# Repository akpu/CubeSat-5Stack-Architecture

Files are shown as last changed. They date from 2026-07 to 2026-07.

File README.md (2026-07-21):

# Open-Source ESP32 CubeSat 5-Stack Electronics Architecture with LoRa, APRS, SSTV and WSPR Telemetry 🛰️

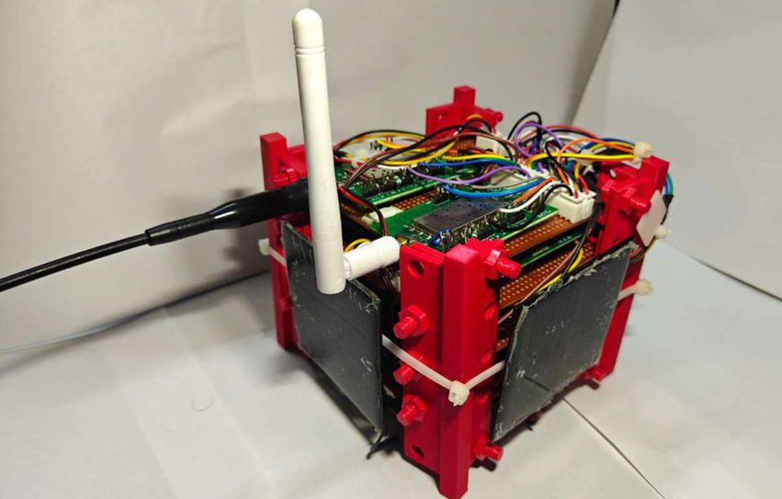
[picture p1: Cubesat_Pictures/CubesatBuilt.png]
CubeSat Assembly


A modular **1U CubeSat electronic stack** developed for balloon-based communication and telemetry experiments.

This project focuses on the design, development, integration, and validation of a complete CubeSat electronics platform consisting of five modular PCB subsystems, embedded firmware, ground station software, and 3D mechanical integration.

---

# System Architecture

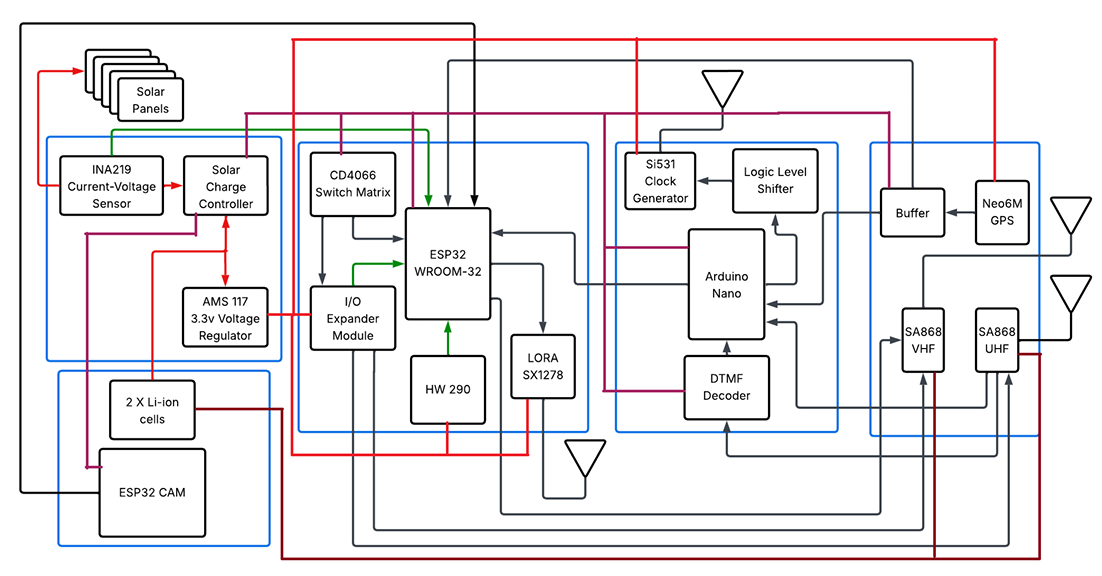
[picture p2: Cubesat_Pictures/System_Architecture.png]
System Architecture


The CubeSat architecture consists of five modular subsystems:

1. Communication Board  
2. Main On-Board Computer (OBC) Board  
3. Secondary Controller Board  
4. Power Management Board  
5. Battery and Payload Board  

---

# Hardware Implementation

The electronics system was designed using **KiCad** with custom schematic and PCB layouts.

Main hardware components:

- ESP32-WROOM-32 based On-Board Computer
- Arduino Nano secondary controller
- LoRa SX1278 telemetry transceiver
- SA868 VHF/UHF communication module
- ESP32-CAM SSTV imaging payload
- Si5351 WSPR beacon transmitter
- Neo-6M GPS module
- HW-290 IMU sensor
- INA219 power monitoring sensor

---

# PCB Stack Assembly

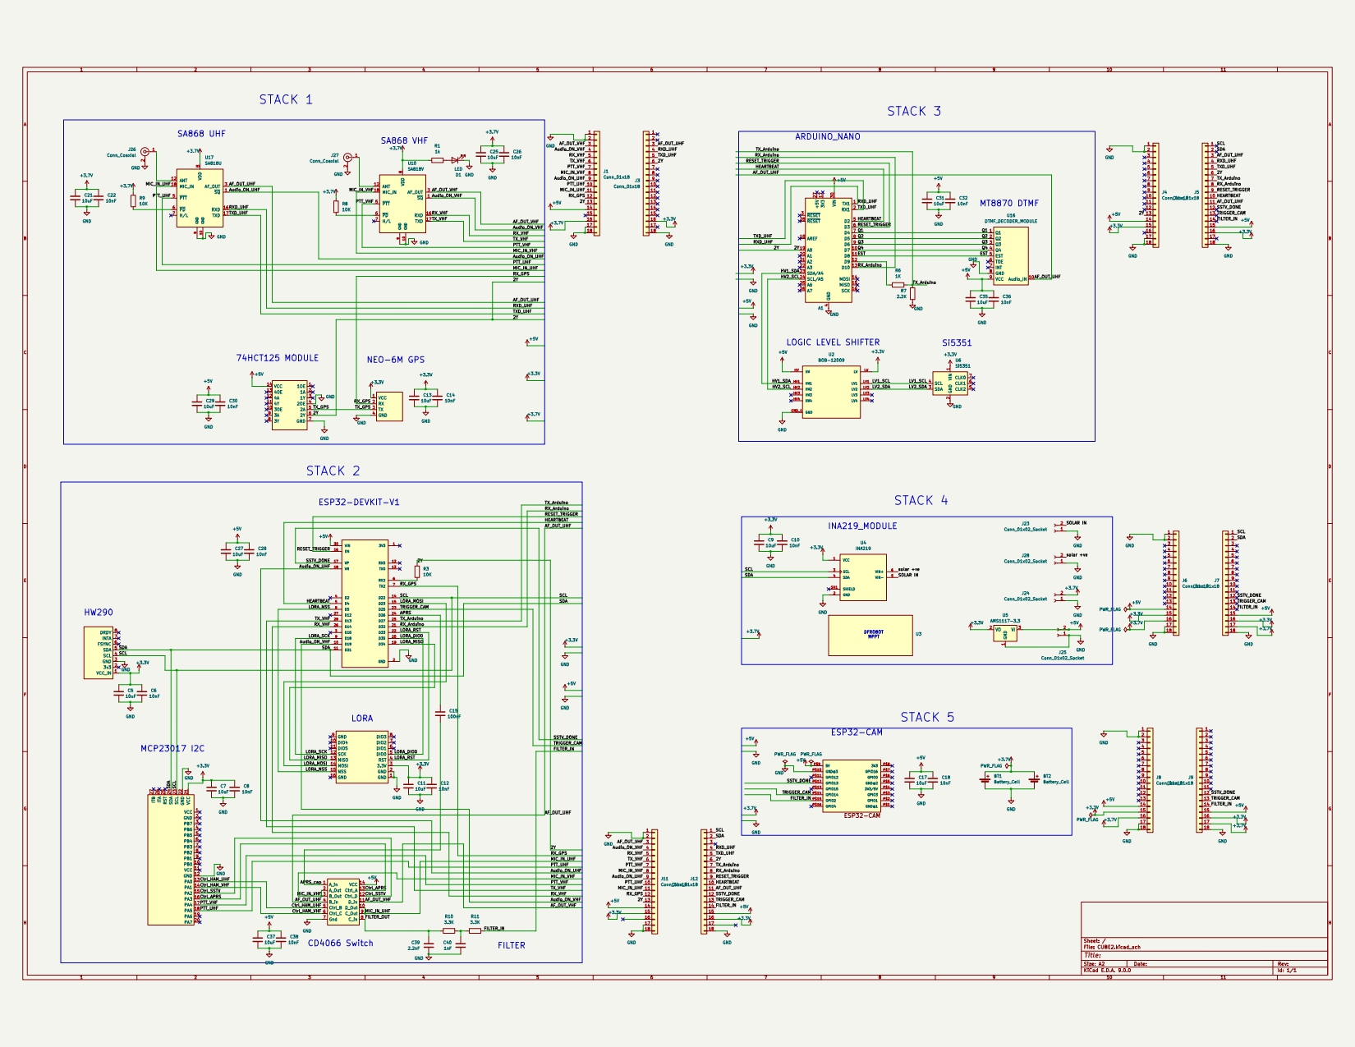
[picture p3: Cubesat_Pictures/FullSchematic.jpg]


The CubeSat electronics were implemented as five vertically stacked PCB modules.

PCB design files are available in:

```
Hardware_Design/
```

Includes:

- KiCad schematic files (`.kicad_sch`)
- PCB layout files (`.kicad_pcb`)
- KiCad project files (`.kicad_pro`)

---
---

<h2>Individual PCB Stack Modules</h2>

<table>
<tr>
<td align="center">
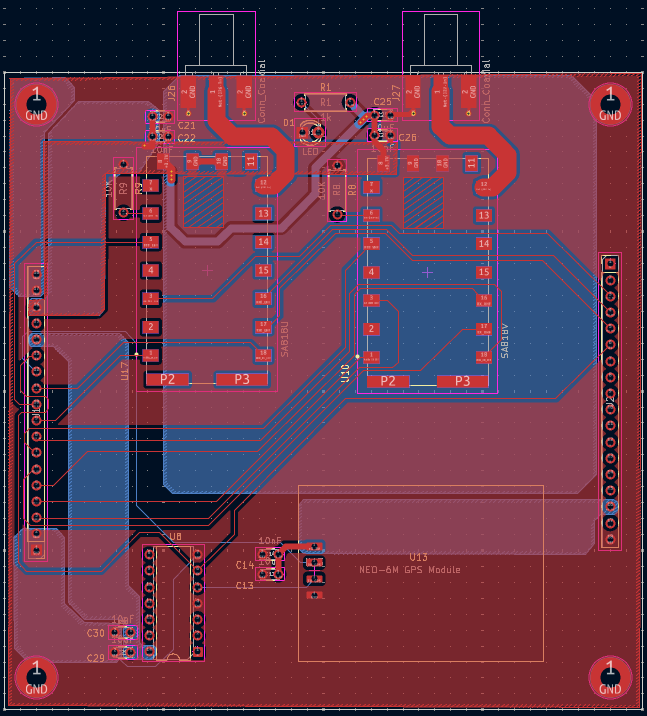
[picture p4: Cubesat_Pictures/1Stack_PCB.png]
<br>
<b>Communication Board</b>
</td>

<td align="center">
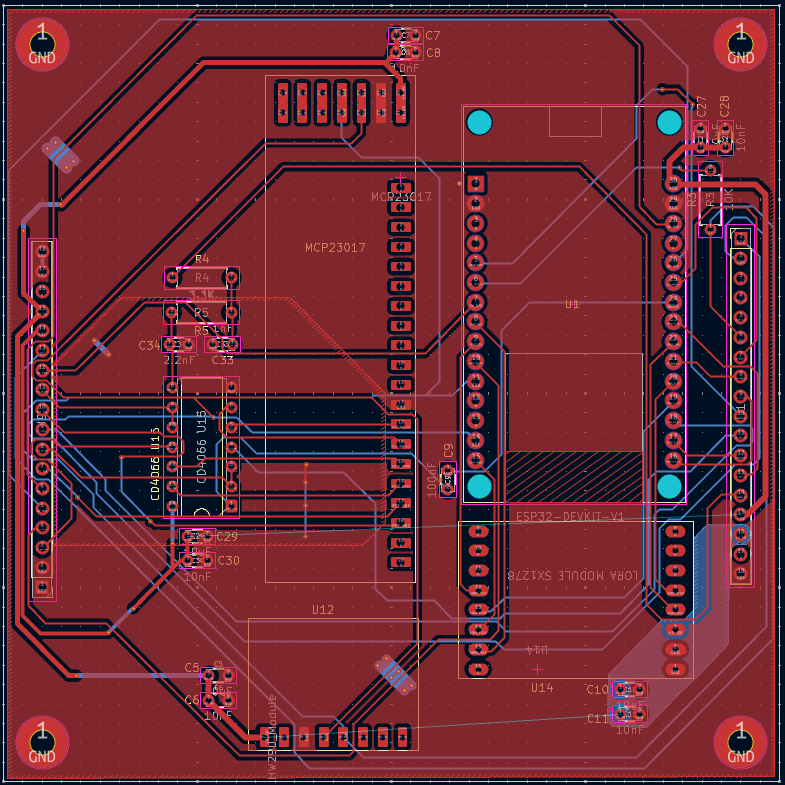
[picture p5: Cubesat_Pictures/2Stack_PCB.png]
<br>
<b>Main OBC Board</b>
</td>

<td align="center">
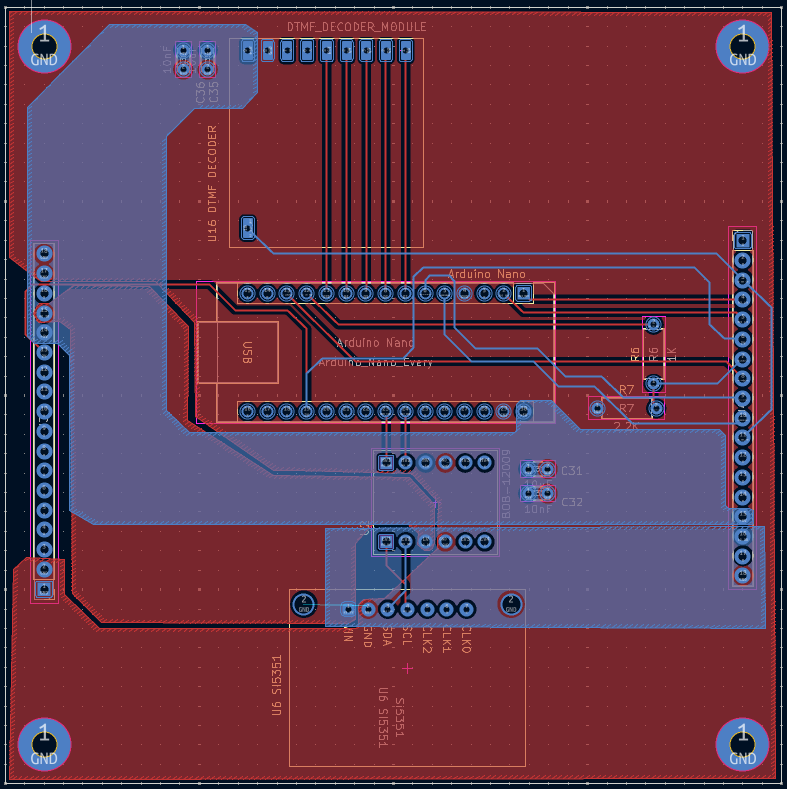
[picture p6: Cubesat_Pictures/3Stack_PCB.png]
<br>
<b>Secondary Controller Board</b>
</td>
</tr>

<tr>
<td align="center">
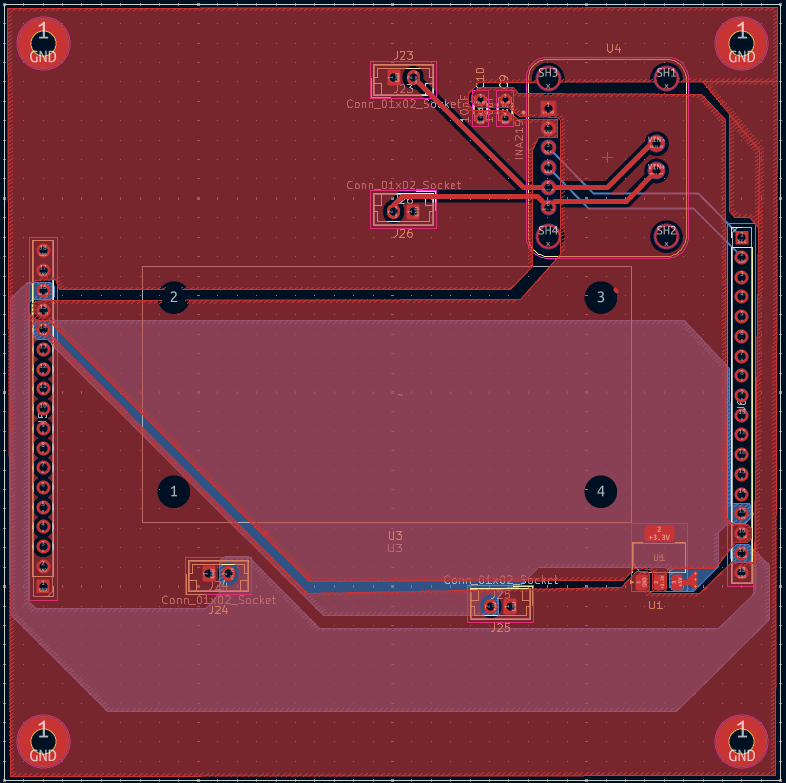
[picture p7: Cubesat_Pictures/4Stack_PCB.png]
<br>
<b>Power Management Board</b>
</td>

<td align="center">
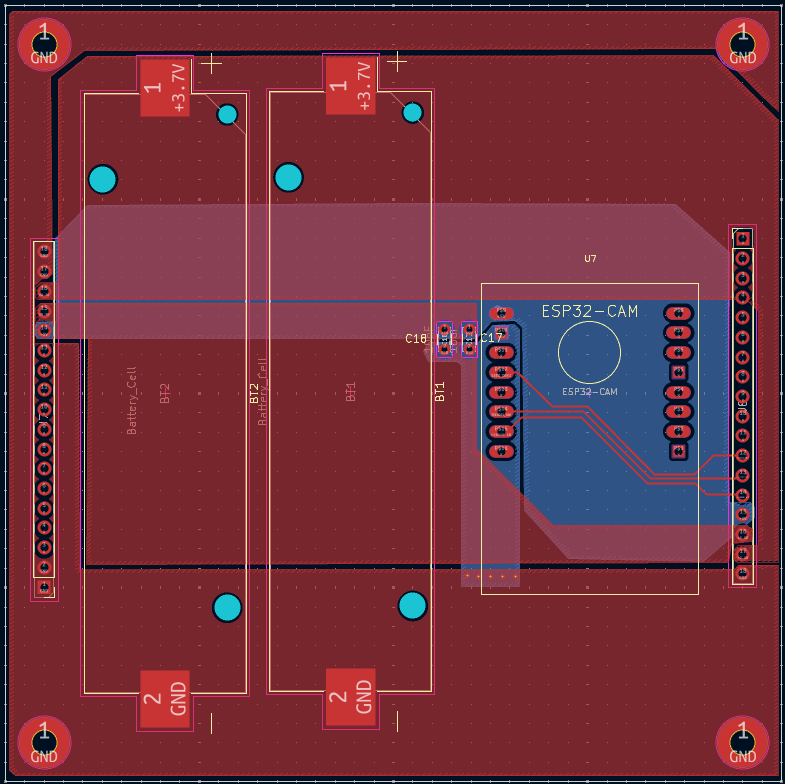
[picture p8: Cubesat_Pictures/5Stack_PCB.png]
<br>
<b>Battery & Payload Board</b>
</td>
</tr>
</table>

# 3D Design

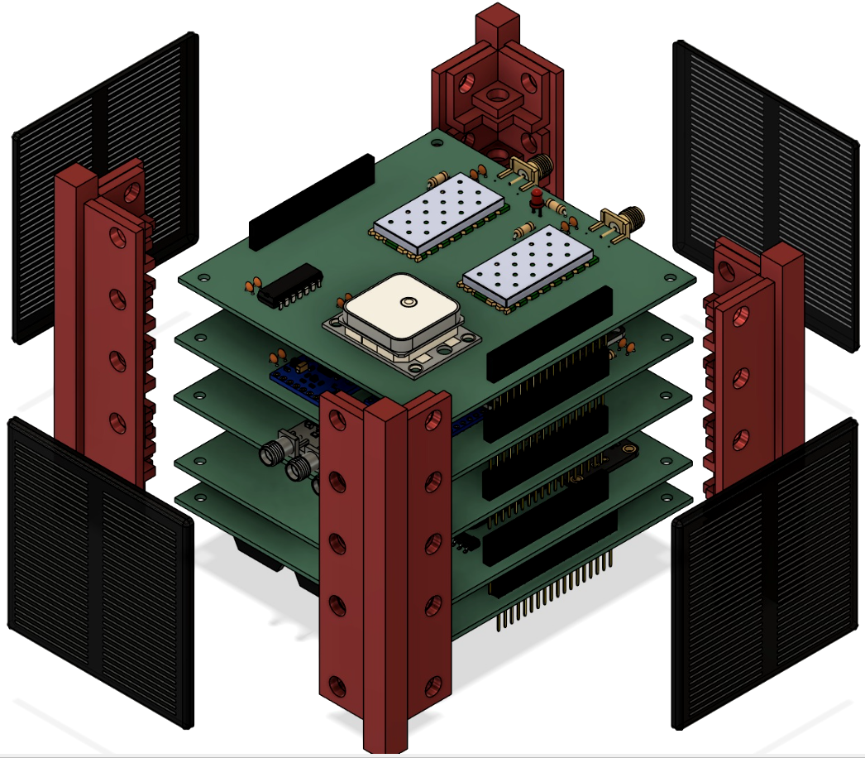
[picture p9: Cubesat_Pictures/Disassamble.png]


The complete CubeSat mechanical structure was designed using:

- Fusion 360

Includes:

- PCB stack integration
- Structural frame design
- Component placement visualization
- Complete assembly model
<h2>Individual PCB Stack Modules</h2>

<table>
<tr>
<td align="center">
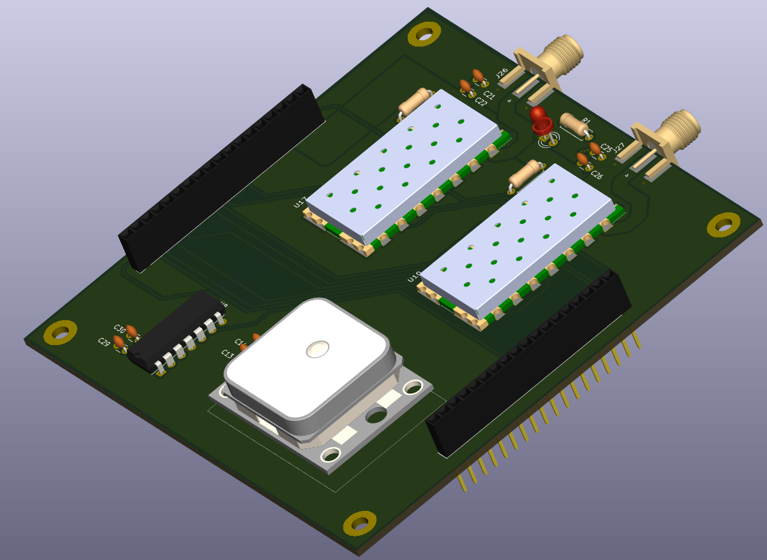
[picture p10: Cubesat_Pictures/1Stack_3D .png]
<br>
<b>Communication Board</b>
</td>

<td align="center">
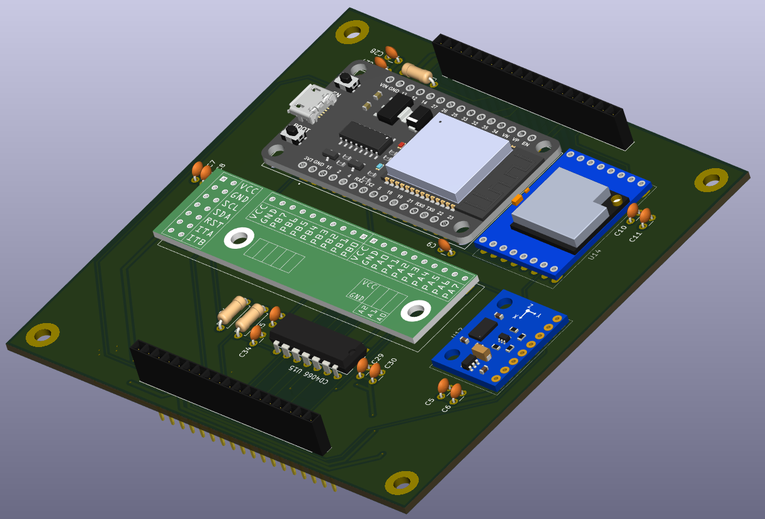
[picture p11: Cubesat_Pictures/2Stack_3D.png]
<br>
<b>Main OBC Board</b>
</td>

<td align="center">
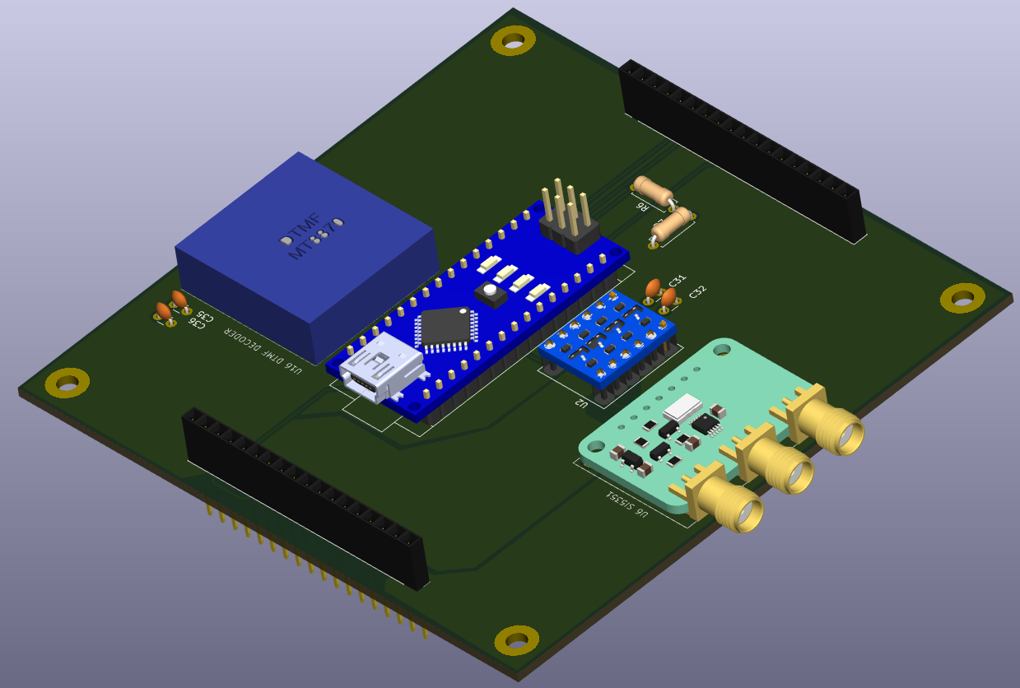
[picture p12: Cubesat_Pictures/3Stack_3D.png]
<br>
<b>Secondary Controller Board</b>
</td>
</tr>

<tr>
<td align="center">
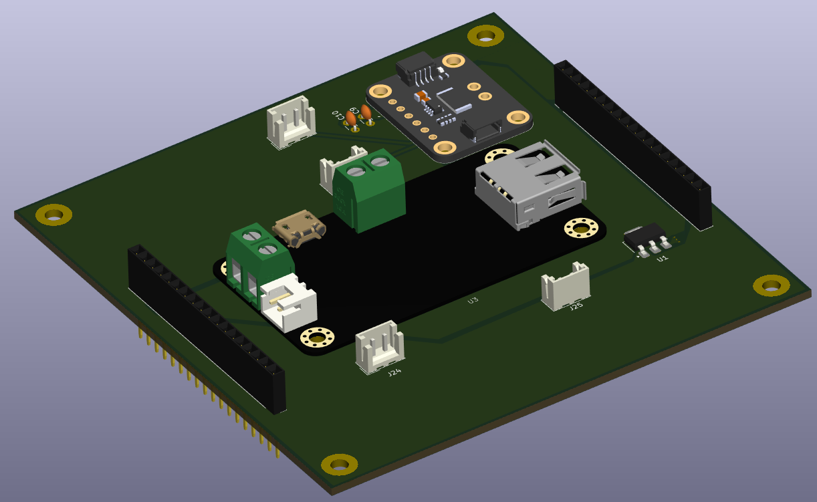
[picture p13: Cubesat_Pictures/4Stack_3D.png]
<br>
<b>Power Management Board</b>
</td>

<td align="center">
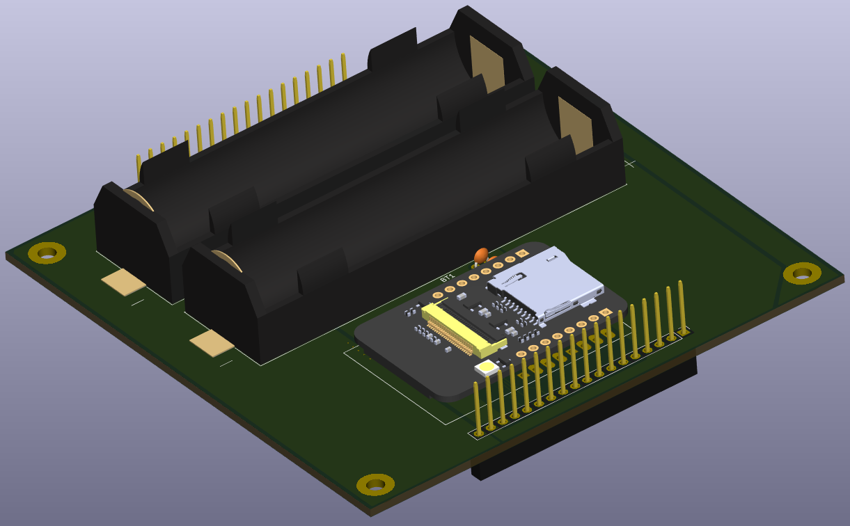
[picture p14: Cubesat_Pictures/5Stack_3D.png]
<br>
<b>Battery & Payload Board</b>
</td>
</tr>
</table>
Files:

```
3D_Design/
```

---

# Firmware Development

Embedded firmware was developed for:

```
Firmware/
```

Includes:

### CubeSat Onboard Firmware

- ESP32 main controller code
- ESP32-CAM SSTV payload code
- Arduino Nano WSPR beacon code

### Ground Station Software

A web-based dashboard was developed for real-time telemetry visualization.

Features:

- GPS position monitoring
- Altitude display
- Sensor data visualization
- Solar Charging monitoring
- Orientation information

---

# Ground Station

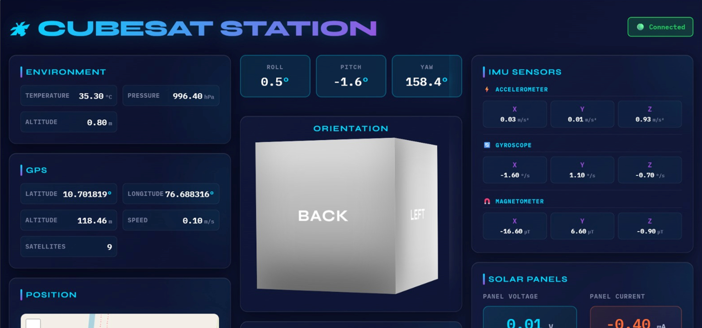
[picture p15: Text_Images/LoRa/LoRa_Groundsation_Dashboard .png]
Ground Station Dashboard


The ground station receives and displays telemetry transmitted from the CubeSat system.

---

# Testing and Validation

The system was validated through rooftop ground-based experiments.

Validated communication modes:

✅ LoRa telemetry transmission  
✅ APRS communication  
✅ SSTV image transmission  
✅ WSPR beacon decoding  

Detailed test results and screenshots:

```
Text_Images/
```

---

# Testing Video

Rooftop demonstration video showing:

- Integrated CubeSat hardware
- Communication testing
- Ground station operation

((https://drive.google.com/file/d/1SzN-sQUl8R-h_qq5jK-UIxGzSsxhfScu/view?usp=drivesdk))

---

# Documentation

Complete project documentation:

```
Documentation/
```

Includes:

- Complete CubeSat Project Report
- Complete System Schematic

---

# Repository Structure

```
CubeSat-5Stack-Architecture

├── Documentation
├── Hardware_Design
├── 3D_Design
├── Firmware
├── Calculations
├── Cubesat_Pictures
├── Text_Images
├── Testing_Video
└── README.md
```

---

# Project Team

**B.Tech Final Year Project**  
Department of Electronics and Communication Engineering  
NSS College of Engineering, Palakkad

Team Members:

- Abhishek B
- Akshay S
- Arunkrishna P U
- Kiran S M

---

# Acknowledgement

Developed as part of the B.Tech Final Year Project under the Department of Electronics and Communication Engineering, NSS College of Engineering, Palakkad.

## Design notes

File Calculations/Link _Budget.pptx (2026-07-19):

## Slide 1

Link Margin = Pr − Sensitivity

Link Margin: Difference between received power and receiver sensitivity; positive margin means reliable communication.

• Pt – Transmit power (dBm)
• Gt, Gr – Antenna gains (dBi)
• FSPL – Free-space path loss
• Losses – Cable, connectors, mismatch, fade
• Sensitivity – Receiver minimum detectable power

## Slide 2

VHF Antenna (at Cubesat & Ground Station)

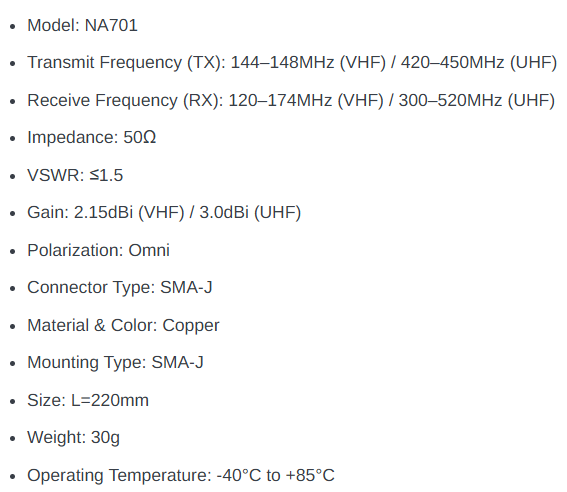
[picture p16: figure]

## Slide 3

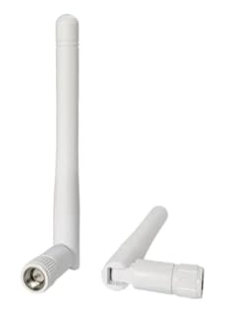
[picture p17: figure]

Lora Antenna for Uplink and Downlink

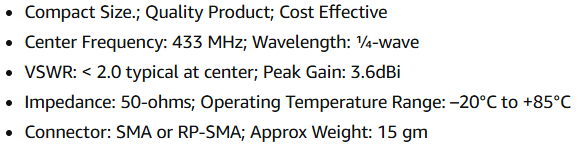
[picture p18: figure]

FSPL CALCULATION (433MHz LoRa)
LFSPL = 32.44 + 20log(433) + 20log(30)
TOTAL FSPL = 32.44 + 52.730 + 29.542 = 114.712 dB

FSPL CALCULATION (145MHz VHF)
LFSPL = 32.44 + 20log(145) + 20log(30)
TOTAL FSPL = 32.44 + 23.223 + 29.542 = 105.205 dB

FSPL CALCULATION (445MHz UHF)
LFSPL = 32.44 + 20log(430) + 20log(30)
TOTAL FSPL = 32.44 + 52.967 + 29.542 = 114.95 dB

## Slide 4

VHF (NA701 Antenna)

Parameter | Value | dB
TX Power (Pt) | 2W SA818 | +33.01 dBm
CubeSat Ant (Gt) | NA701 Quartz | +2.15 dBi
Free Space Loss | 30km @ 145MHz | -105.20 dB
Ground Ant (Gr) | NA701 Quartz | +2.15 dBi
Misc Losses | Cables/Polar | -1.0 dB
Received Power (Pr) | | -71.90 dBm
RTL-SDR Sensitivity | | -110 dBm
LINK MARGIN | | +38.10 dB

UHF (NA701 Antenna)

Parameter | Value | dB
TX Power (Pt) | 2W SA818 | +33.01 dBm
CubeSat Ant (Gt) | NA701 Quartz | +3 dB
Free Space Loss | 30km @ 445MHz | -114.95 dB
Ground Ant (Gr) | NA701 Quartz | +3 dB
Misc Losses | Cables/Polar | -1.0 dB
Received Power (Pr) | | -74.79 dBm
RTL-SDR Sensitivity | | -110 dBm
LINK MARGIN | | +35.21 dB

LoRa Antenna 433Mhz

Parameter | Value | dB
TX Power (Pt) | 100mW SX1278 | +20.00 dBm
CubeSat Ant (Gt) | Sharvi Lora 433MHz | +3.60 dBi
Free Space Loss | 30km @ 433MHz | -114.71 dB
Ground Ant (Gr) | Sharvi Lora 433MHz | +3.60 dBi
Misc Losses | Cables/SWR | -1.0 dB
Received Power (Pr) | | -90.51 dBm
RTL-SDR Sensitivity | | -137 dBm
LINK MARGIN | | +46.49 dB

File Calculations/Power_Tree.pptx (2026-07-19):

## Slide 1

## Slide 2

POWER TREE

DFR0559

5V, 1A

462.4mA

19mA

90mA

150mA

AMS1117S 3.3

191mA

2mA

I/O Expander

3V3, 1A

15.5mA

Si5351

3.7 V, 3.4Ah

2P LGMJI18650

Arduino NANO

2mA

INA219

80mA

NEO 6M

ESP32 WROOM 32

8.5mA

HW-290

ESP32 CAM

83mA

SX1278(Lora)

Req. Energy / hour | 3.36 Wh
Max battery energy | 25.16 Wh
Usable energy (70%) | 17.61 Wh
Backup time | ≈ 5.2 h
Est. Flight Time | = 3-4 h

0.4mA

74HCT125

1060mA

9mA

DTMF

60mA

SA868 (VHF)

1000mA

SA868 (UHF)

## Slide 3

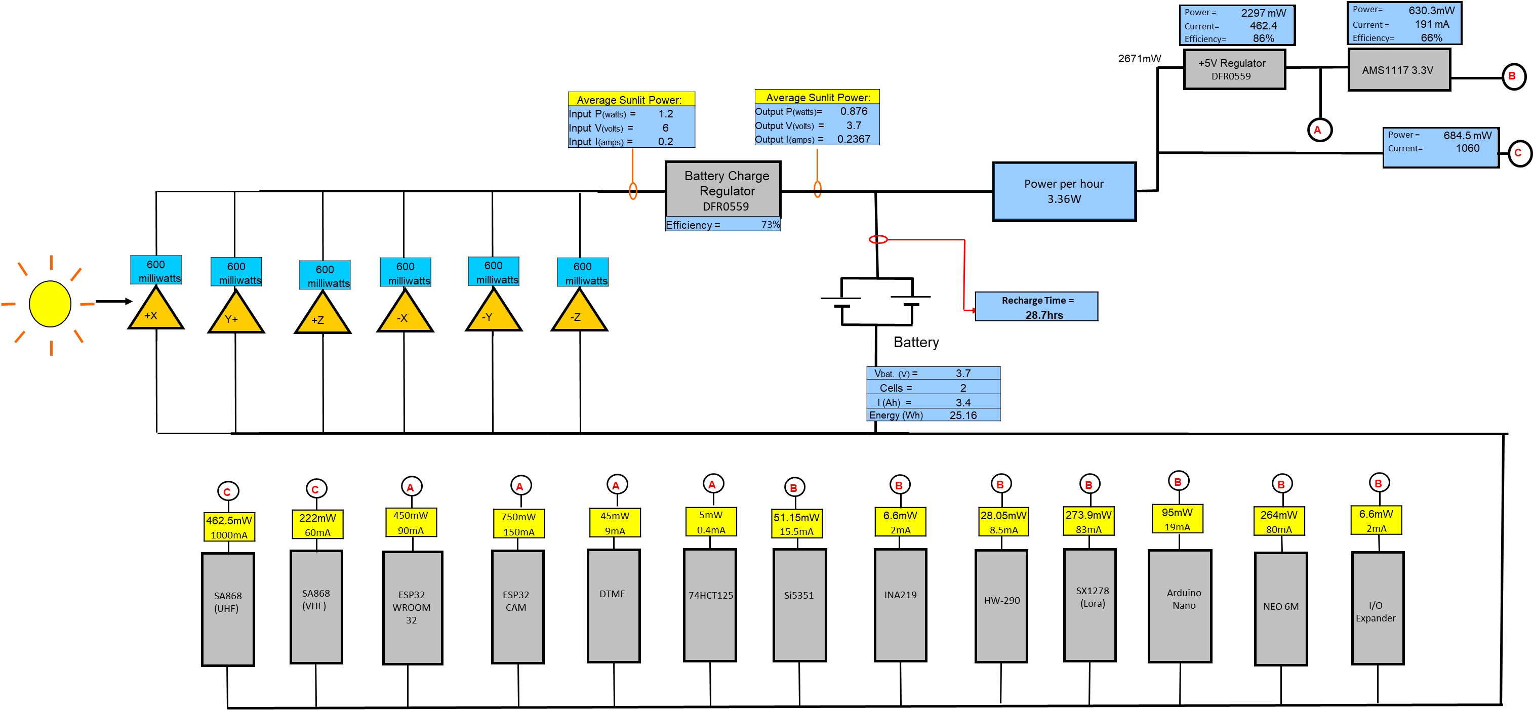
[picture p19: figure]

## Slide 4

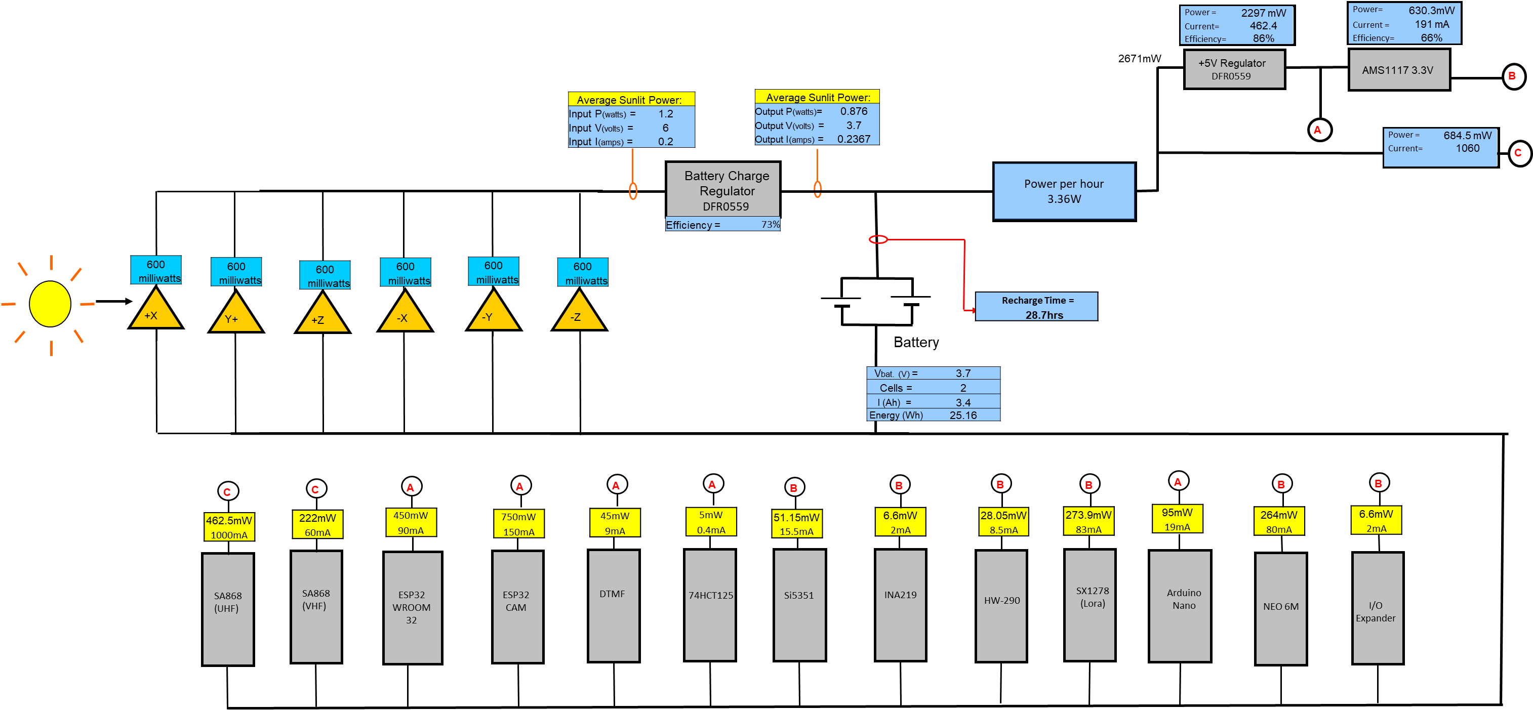
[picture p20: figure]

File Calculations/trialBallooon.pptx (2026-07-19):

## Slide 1

PERMISSION and REGULATIONS

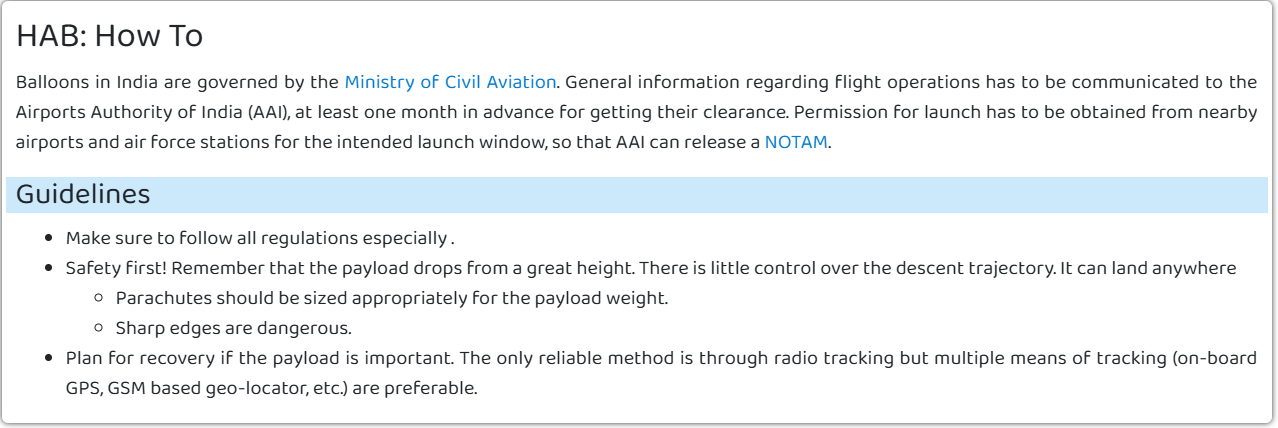
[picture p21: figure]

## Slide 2

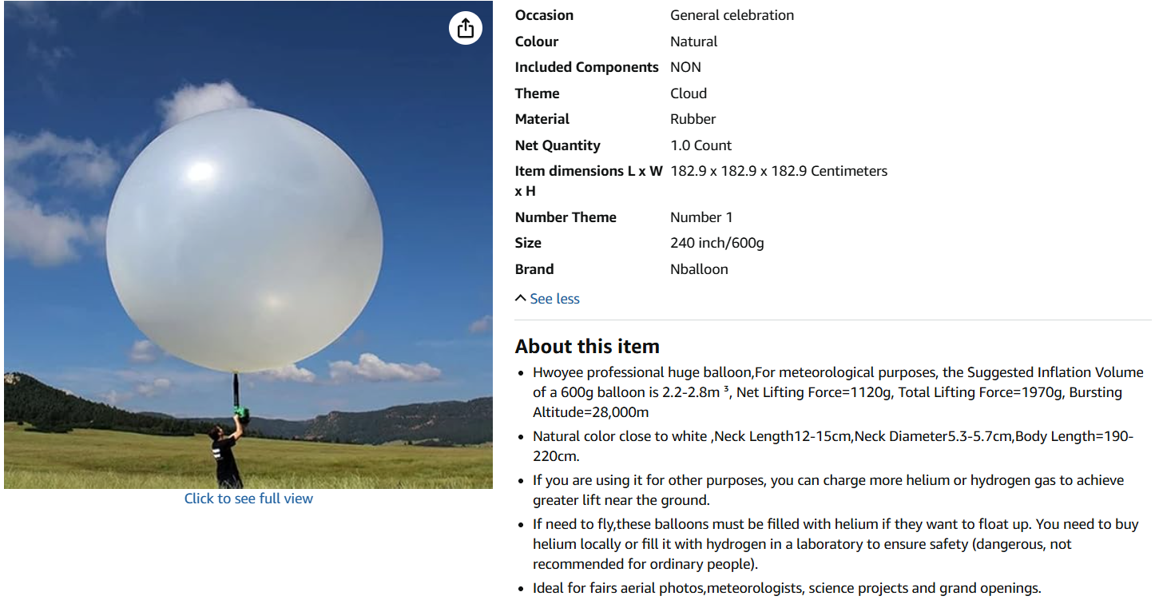
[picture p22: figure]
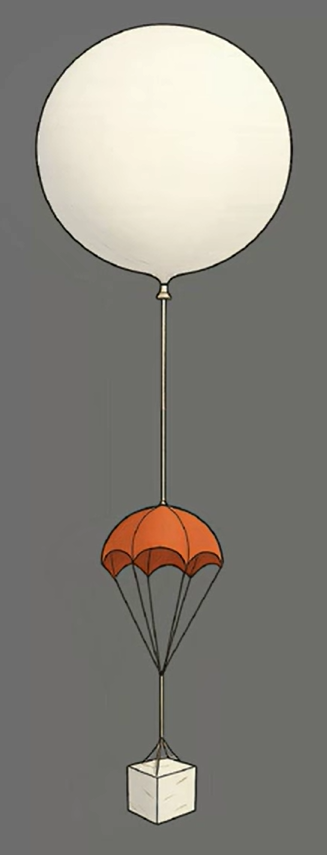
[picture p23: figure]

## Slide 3

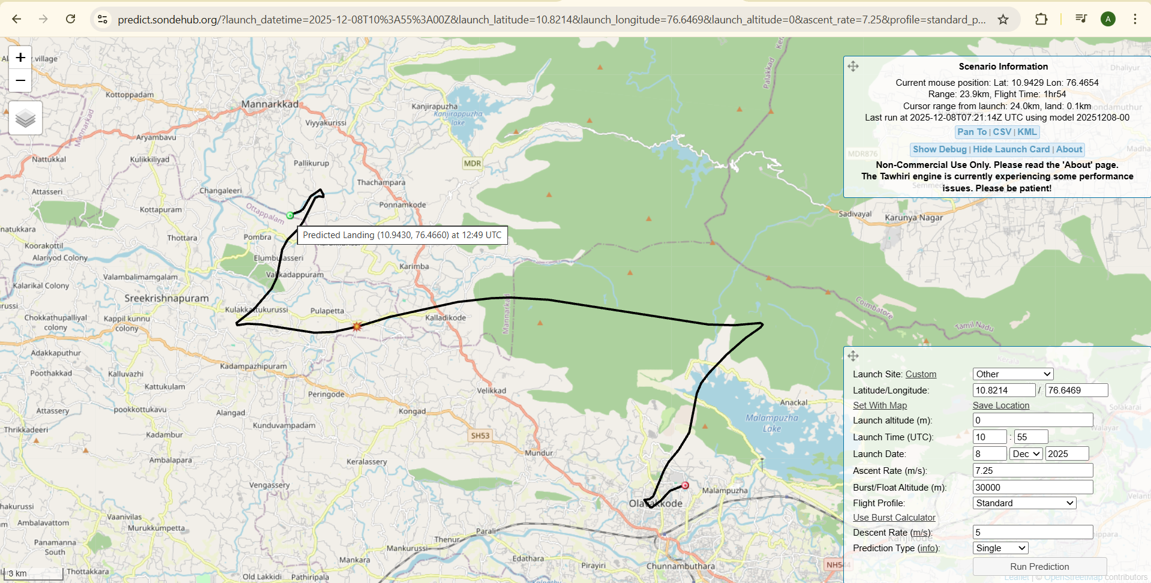
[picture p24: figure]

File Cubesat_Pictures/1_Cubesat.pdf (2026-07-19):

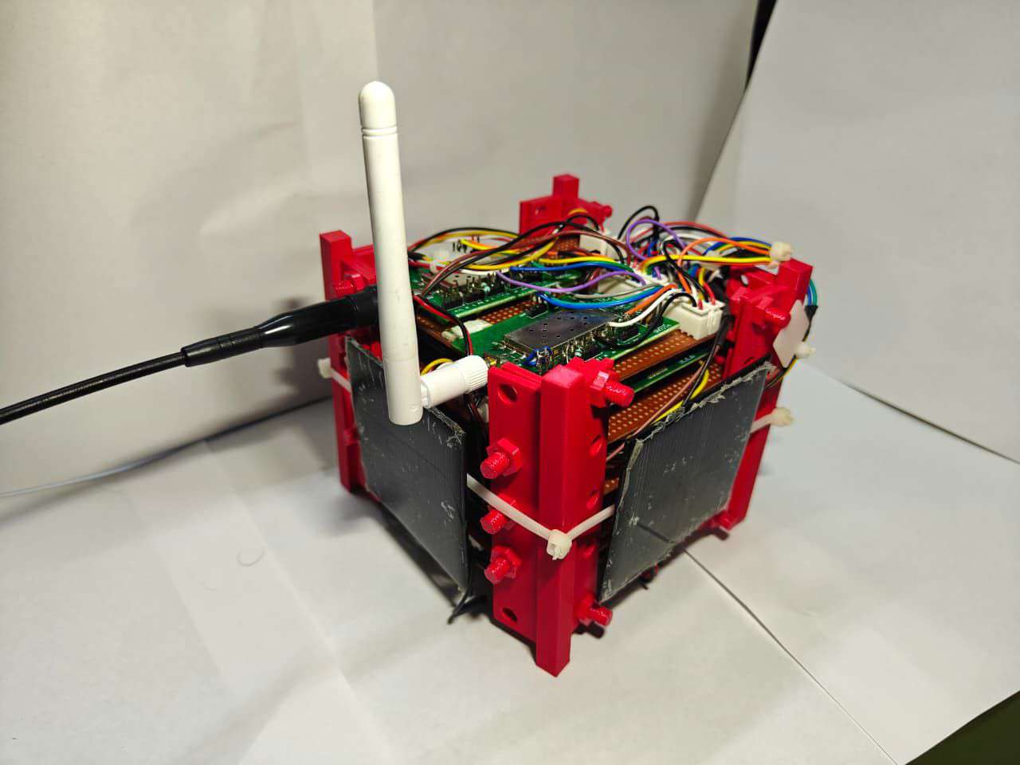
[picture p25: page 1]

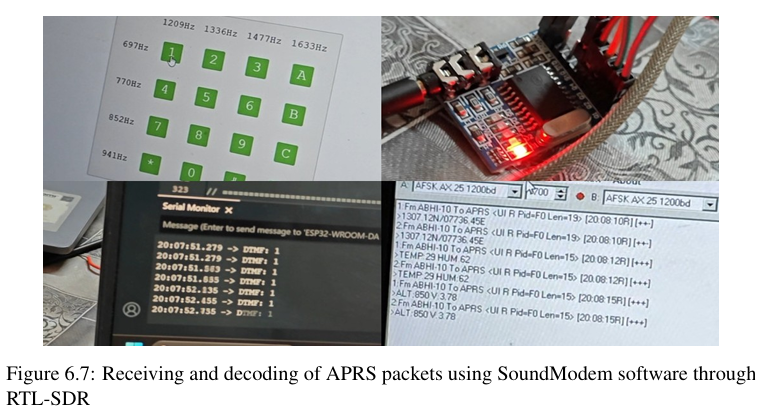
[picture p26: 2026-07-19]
Text_Images/APRS/Tx&Rx.png

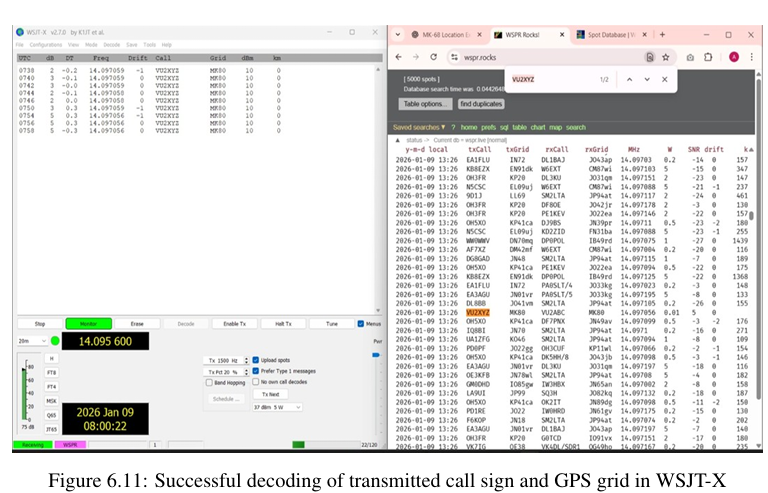
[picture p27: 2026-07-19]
Text_Images/WSPR/WSJT-X.png

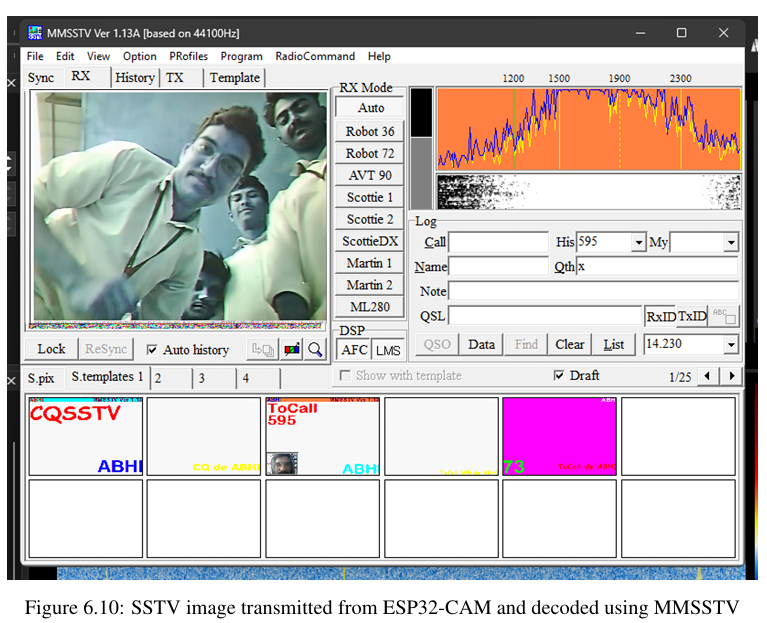
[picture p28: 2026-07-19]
Text_Images/SSTV/SSTV_trial.png

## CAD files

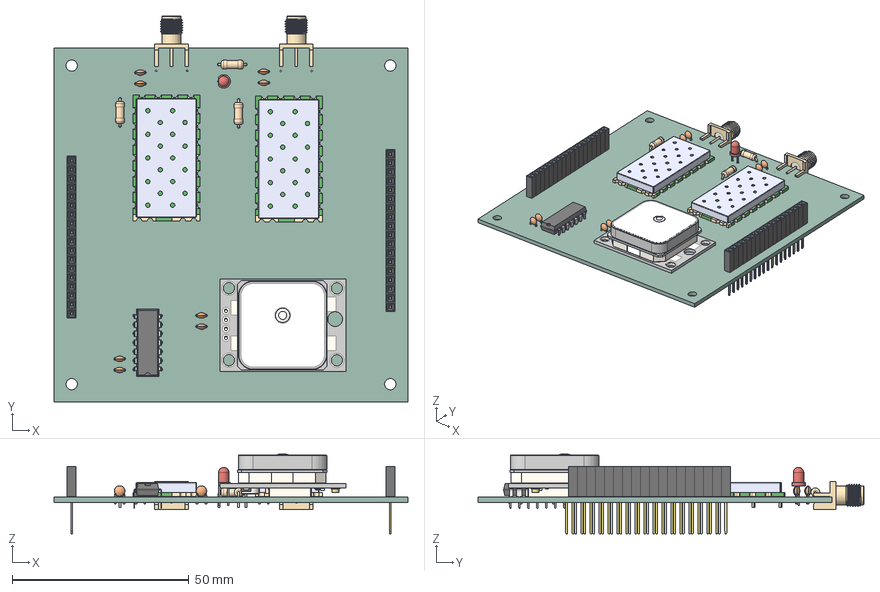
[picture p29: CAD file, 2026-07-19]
Hardware_Design/Stack_1_Communication/1stack.step
100.0 x 109.0 x 22.5 mm
DIP-14_W7.62mm
SIL_Socket_Body x 2
SIL_SocketPin x 2
GPS_ublox_board
GPS_board
GPS_ant
GPS_back
C_Disc_D3.0mm_W1.6mm_P2.50mm x 8
R_Axial_DIN0207_L6.3mm_D2.5mm_P7.62mm_Horizontal x 3
SMA_Molex_73251-1153_EdgeMount_Horizontal x 2
DRA818V x 2
LED_D3.0mm
1stack_PCB

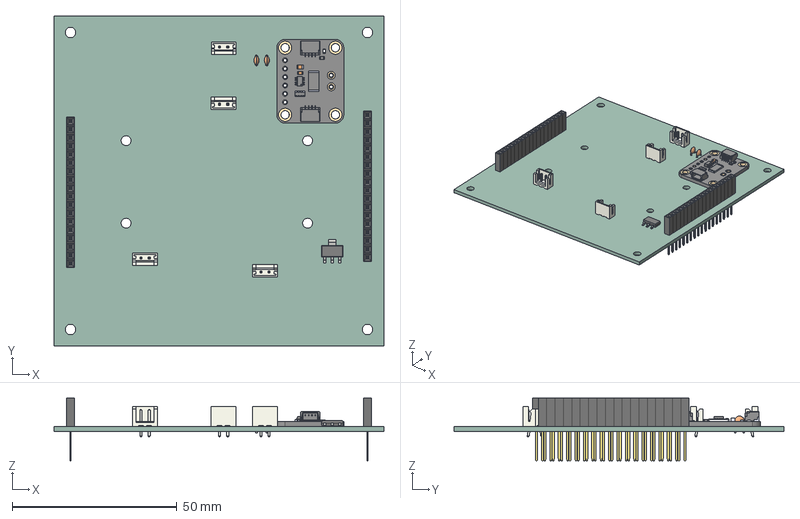
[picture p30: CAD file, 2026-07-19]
Hardware_Design/Stack_4_Power_Management/4 stack.step
100.0 x 100.0 x 19.0 mm
JST_EH_B2B-EH-A_1x02_P2.50mm_Vertical x 4
SOT-223
INA219BIDCNT_INA219BIDCNT1
SM04B-SRSS-TB(LF)(SN) x 2
SIL_Socket_Body x 2
SIL_SocketPin x 2
C_Disc_D3.0mm_W1.6mm_P2.50mm x 2
4 stack_PCB

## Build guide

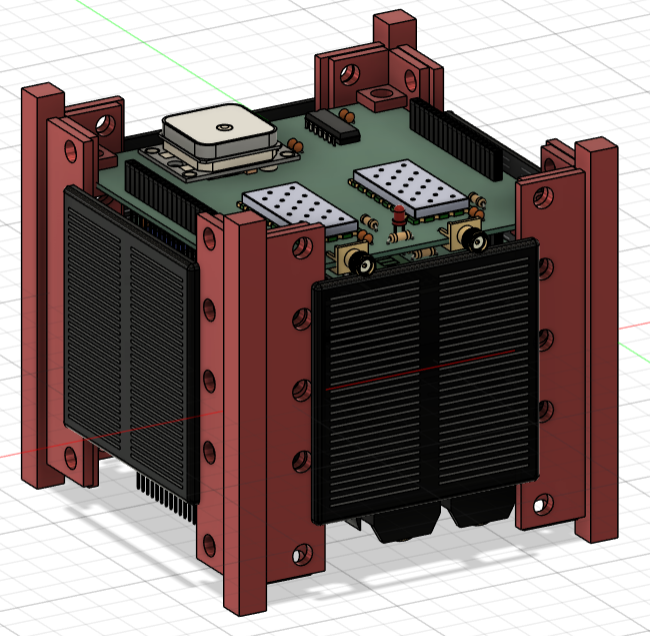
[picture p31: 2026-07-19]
Cubesat_Pictures/FULLASSEMBLE.png

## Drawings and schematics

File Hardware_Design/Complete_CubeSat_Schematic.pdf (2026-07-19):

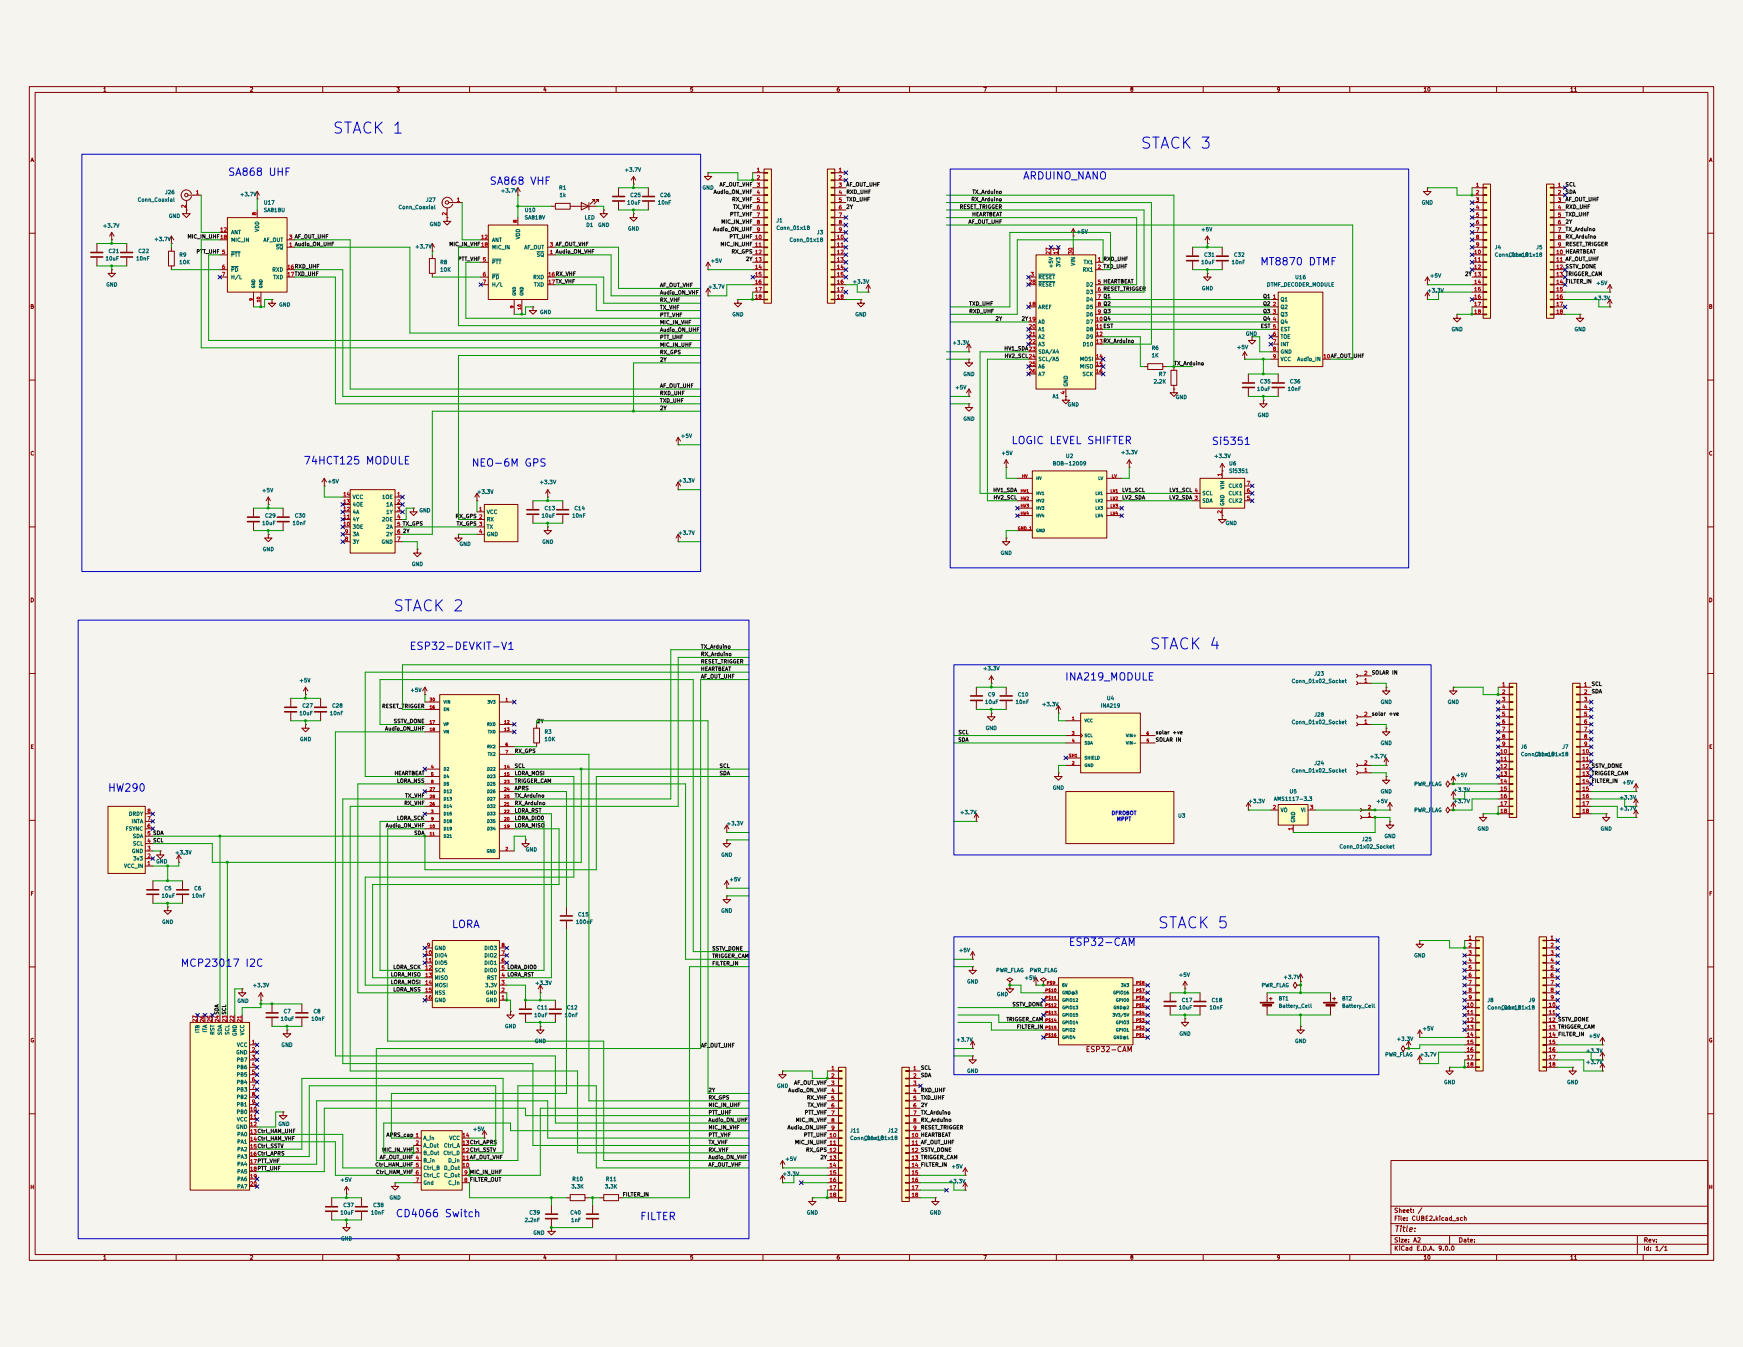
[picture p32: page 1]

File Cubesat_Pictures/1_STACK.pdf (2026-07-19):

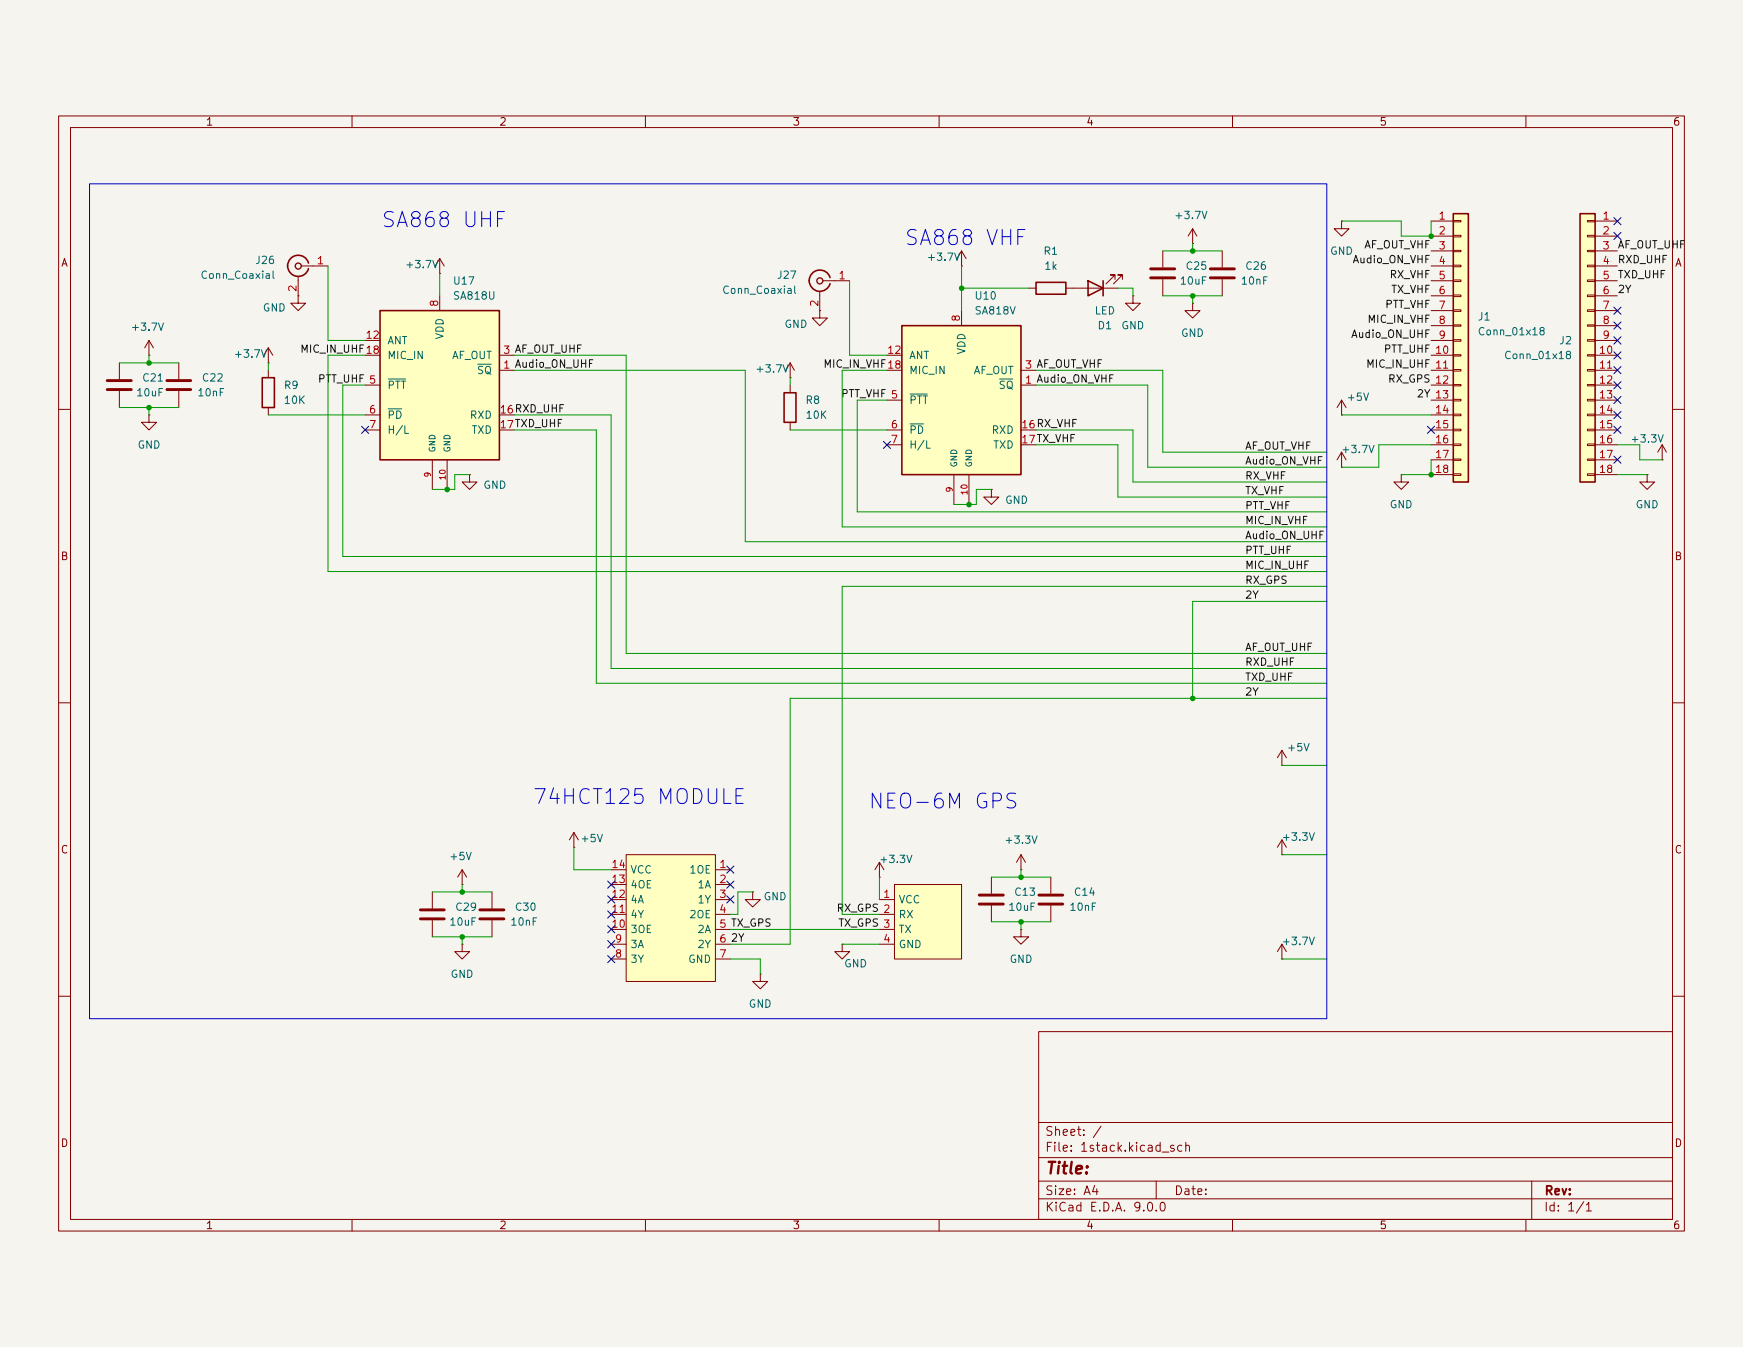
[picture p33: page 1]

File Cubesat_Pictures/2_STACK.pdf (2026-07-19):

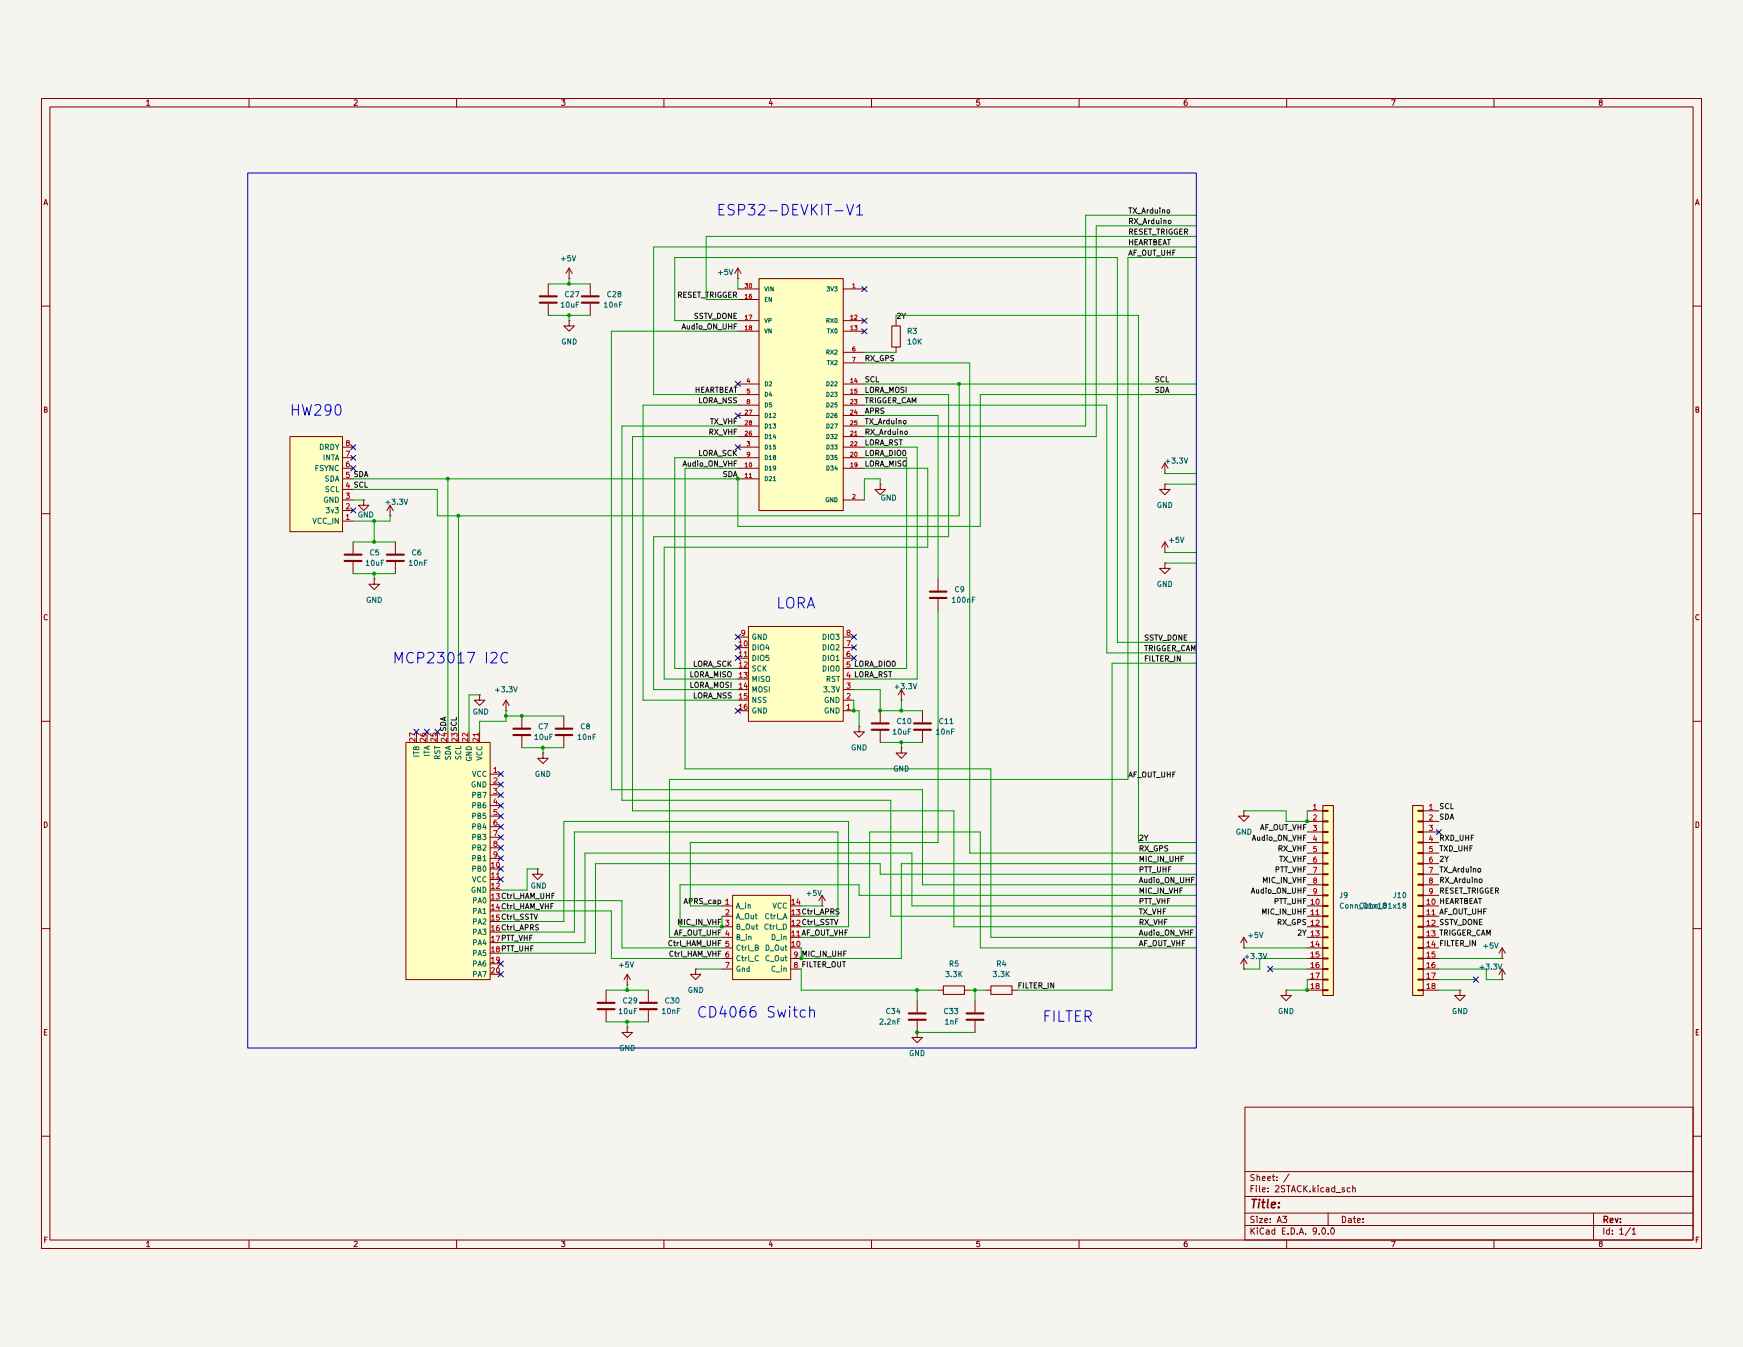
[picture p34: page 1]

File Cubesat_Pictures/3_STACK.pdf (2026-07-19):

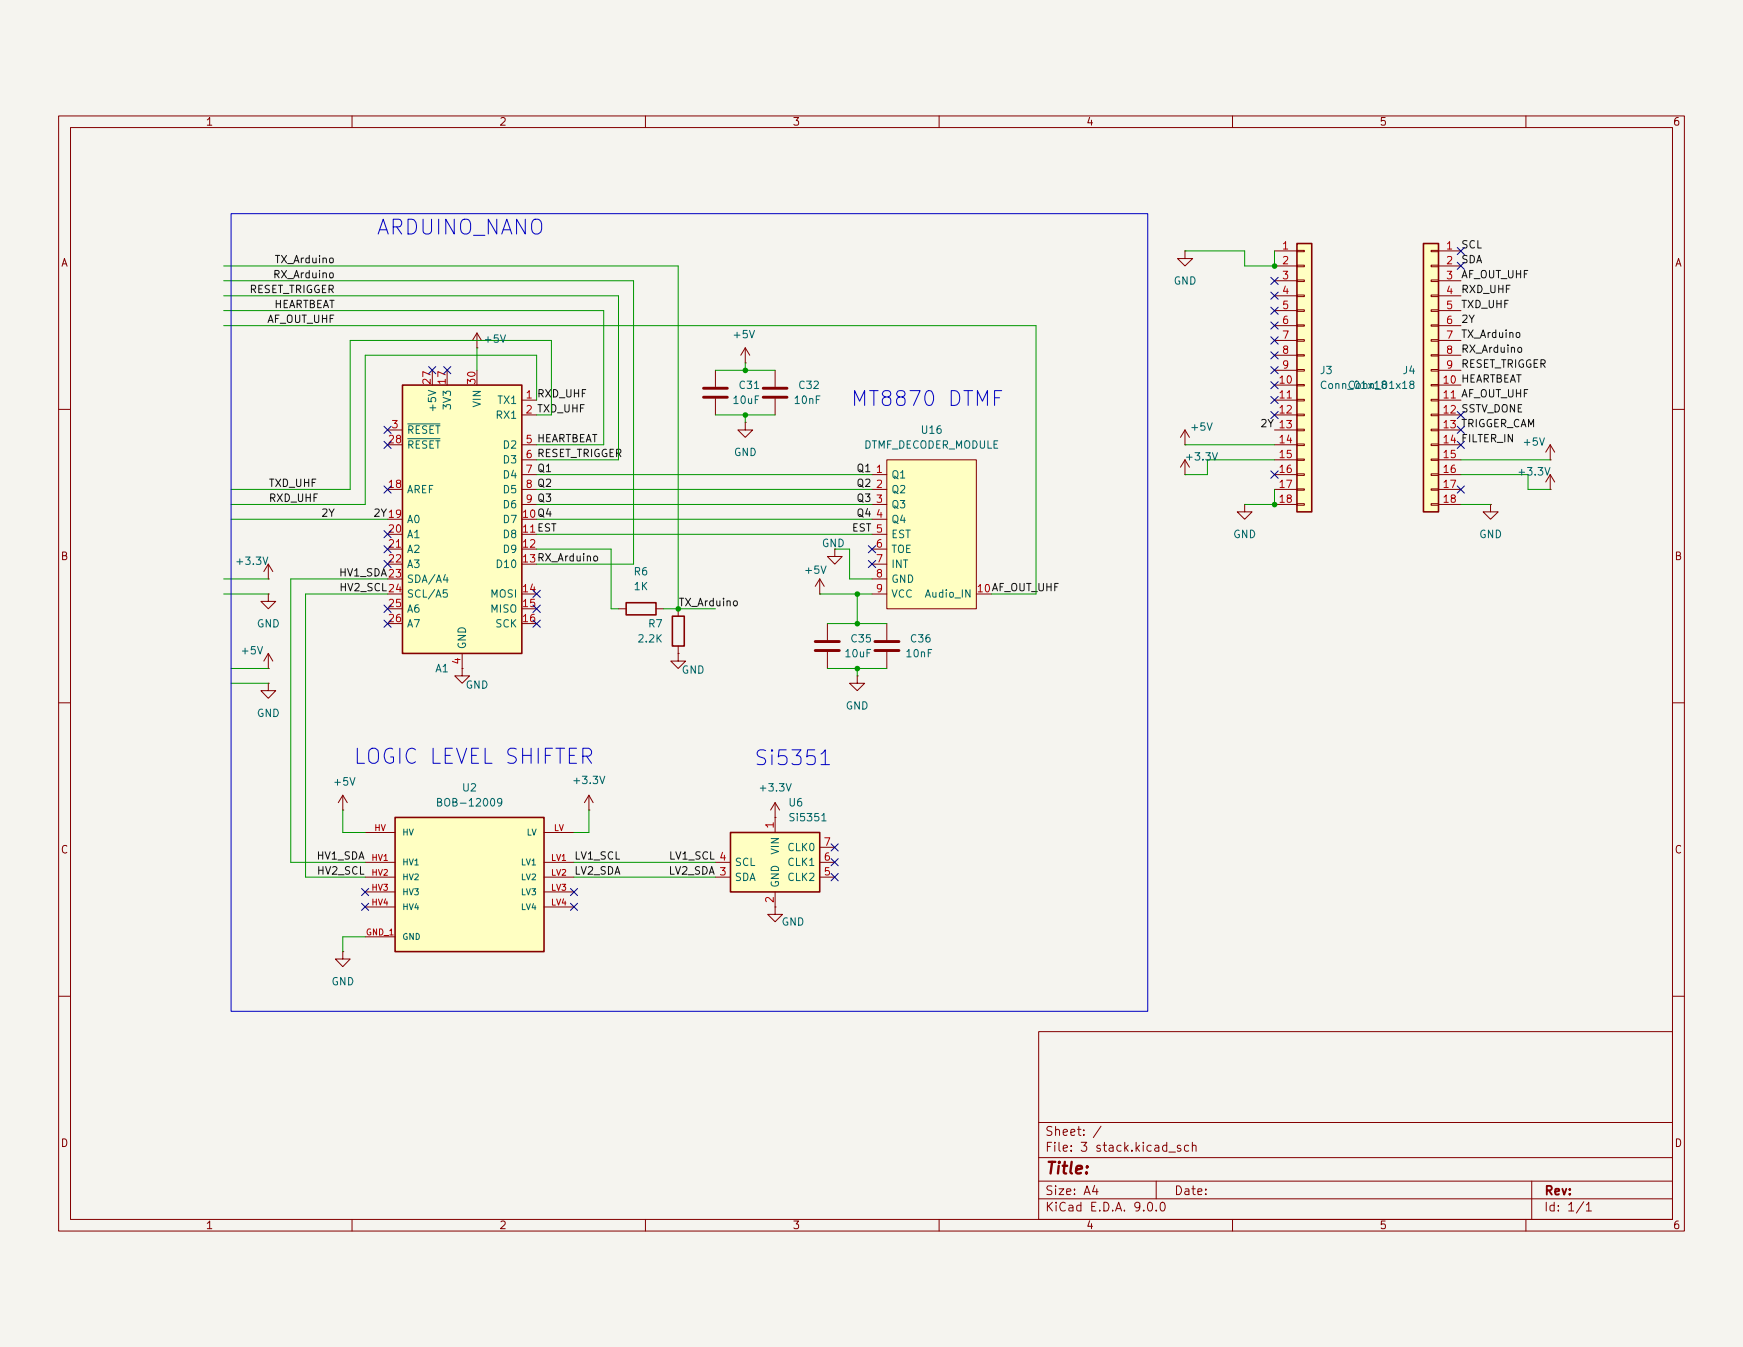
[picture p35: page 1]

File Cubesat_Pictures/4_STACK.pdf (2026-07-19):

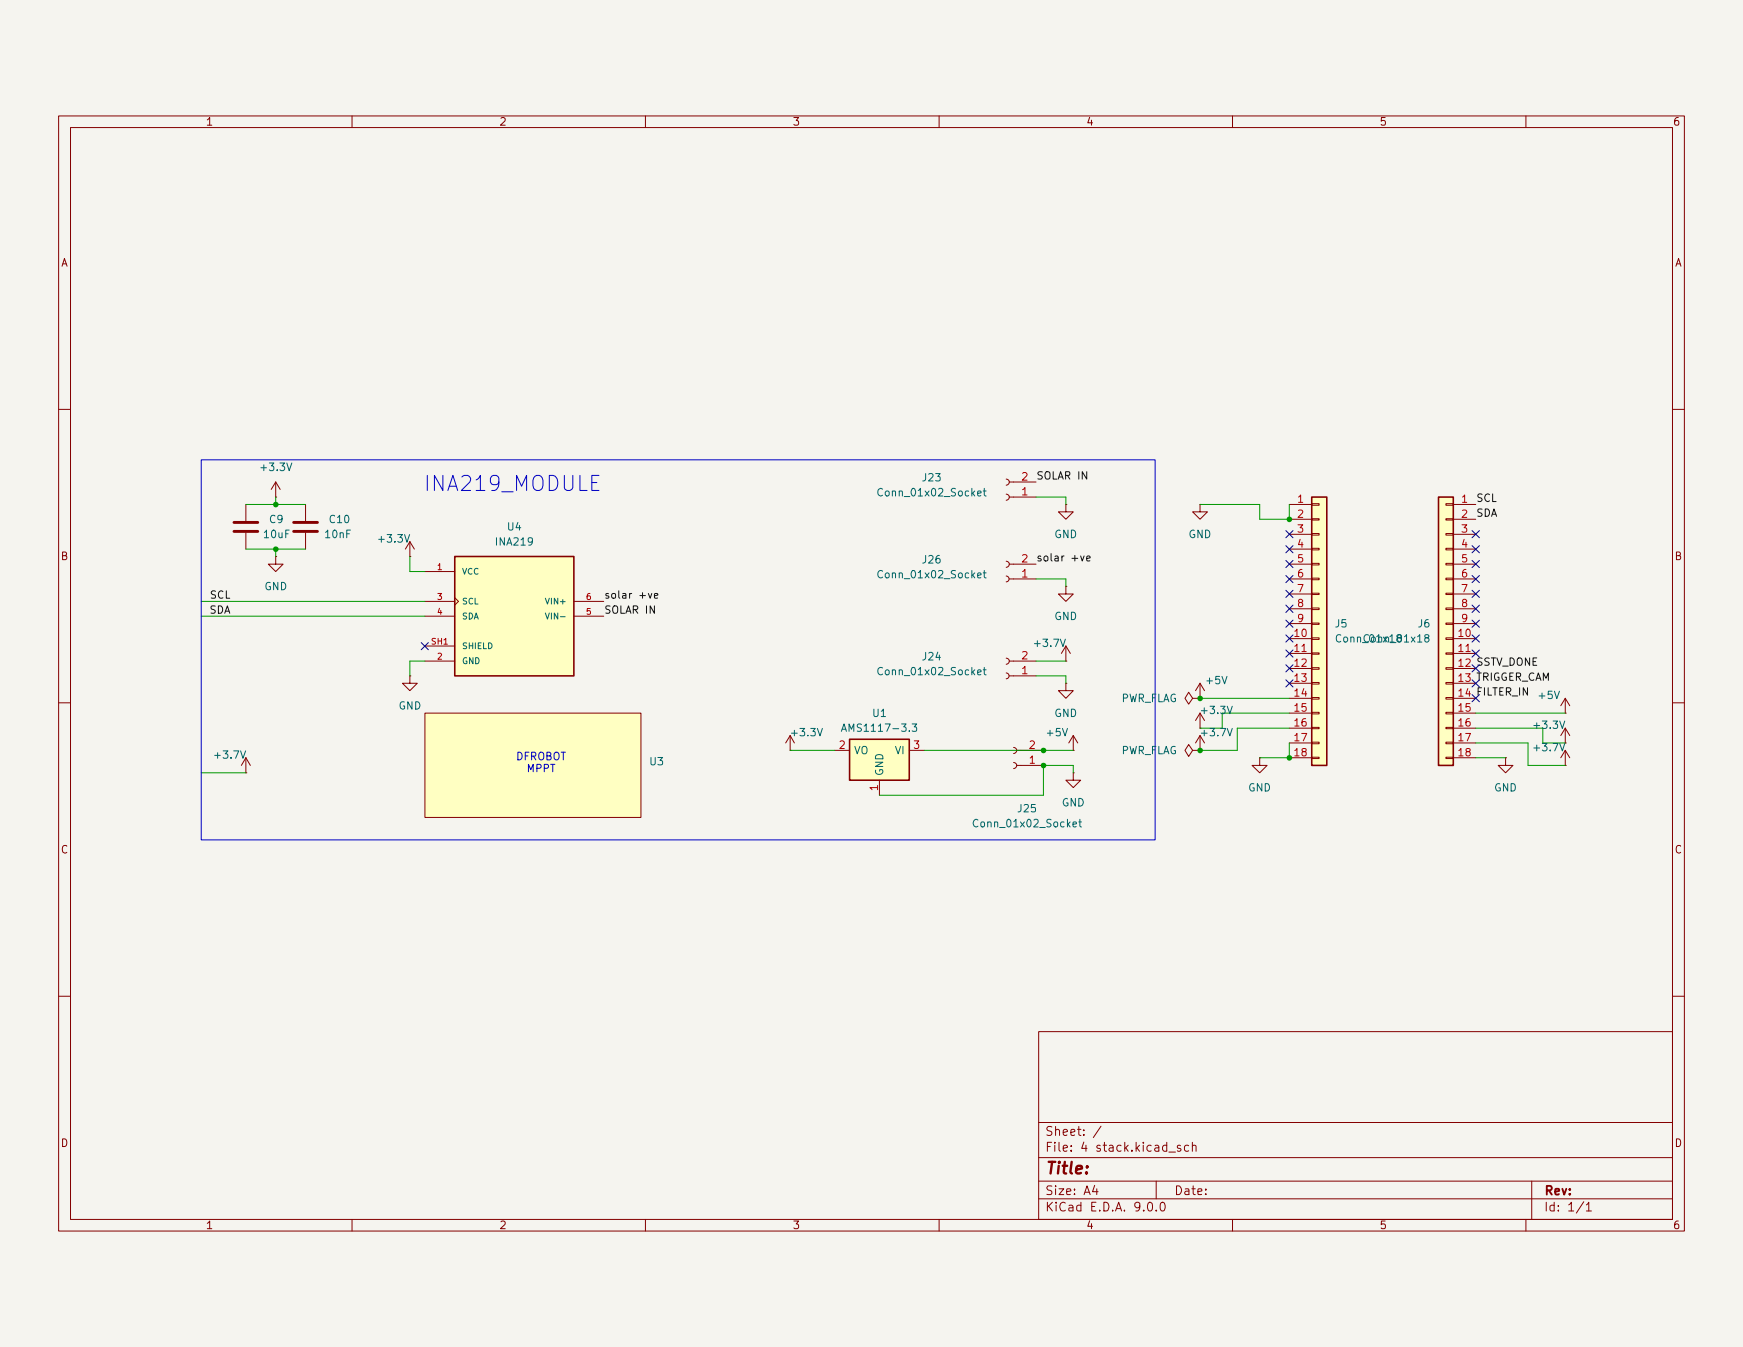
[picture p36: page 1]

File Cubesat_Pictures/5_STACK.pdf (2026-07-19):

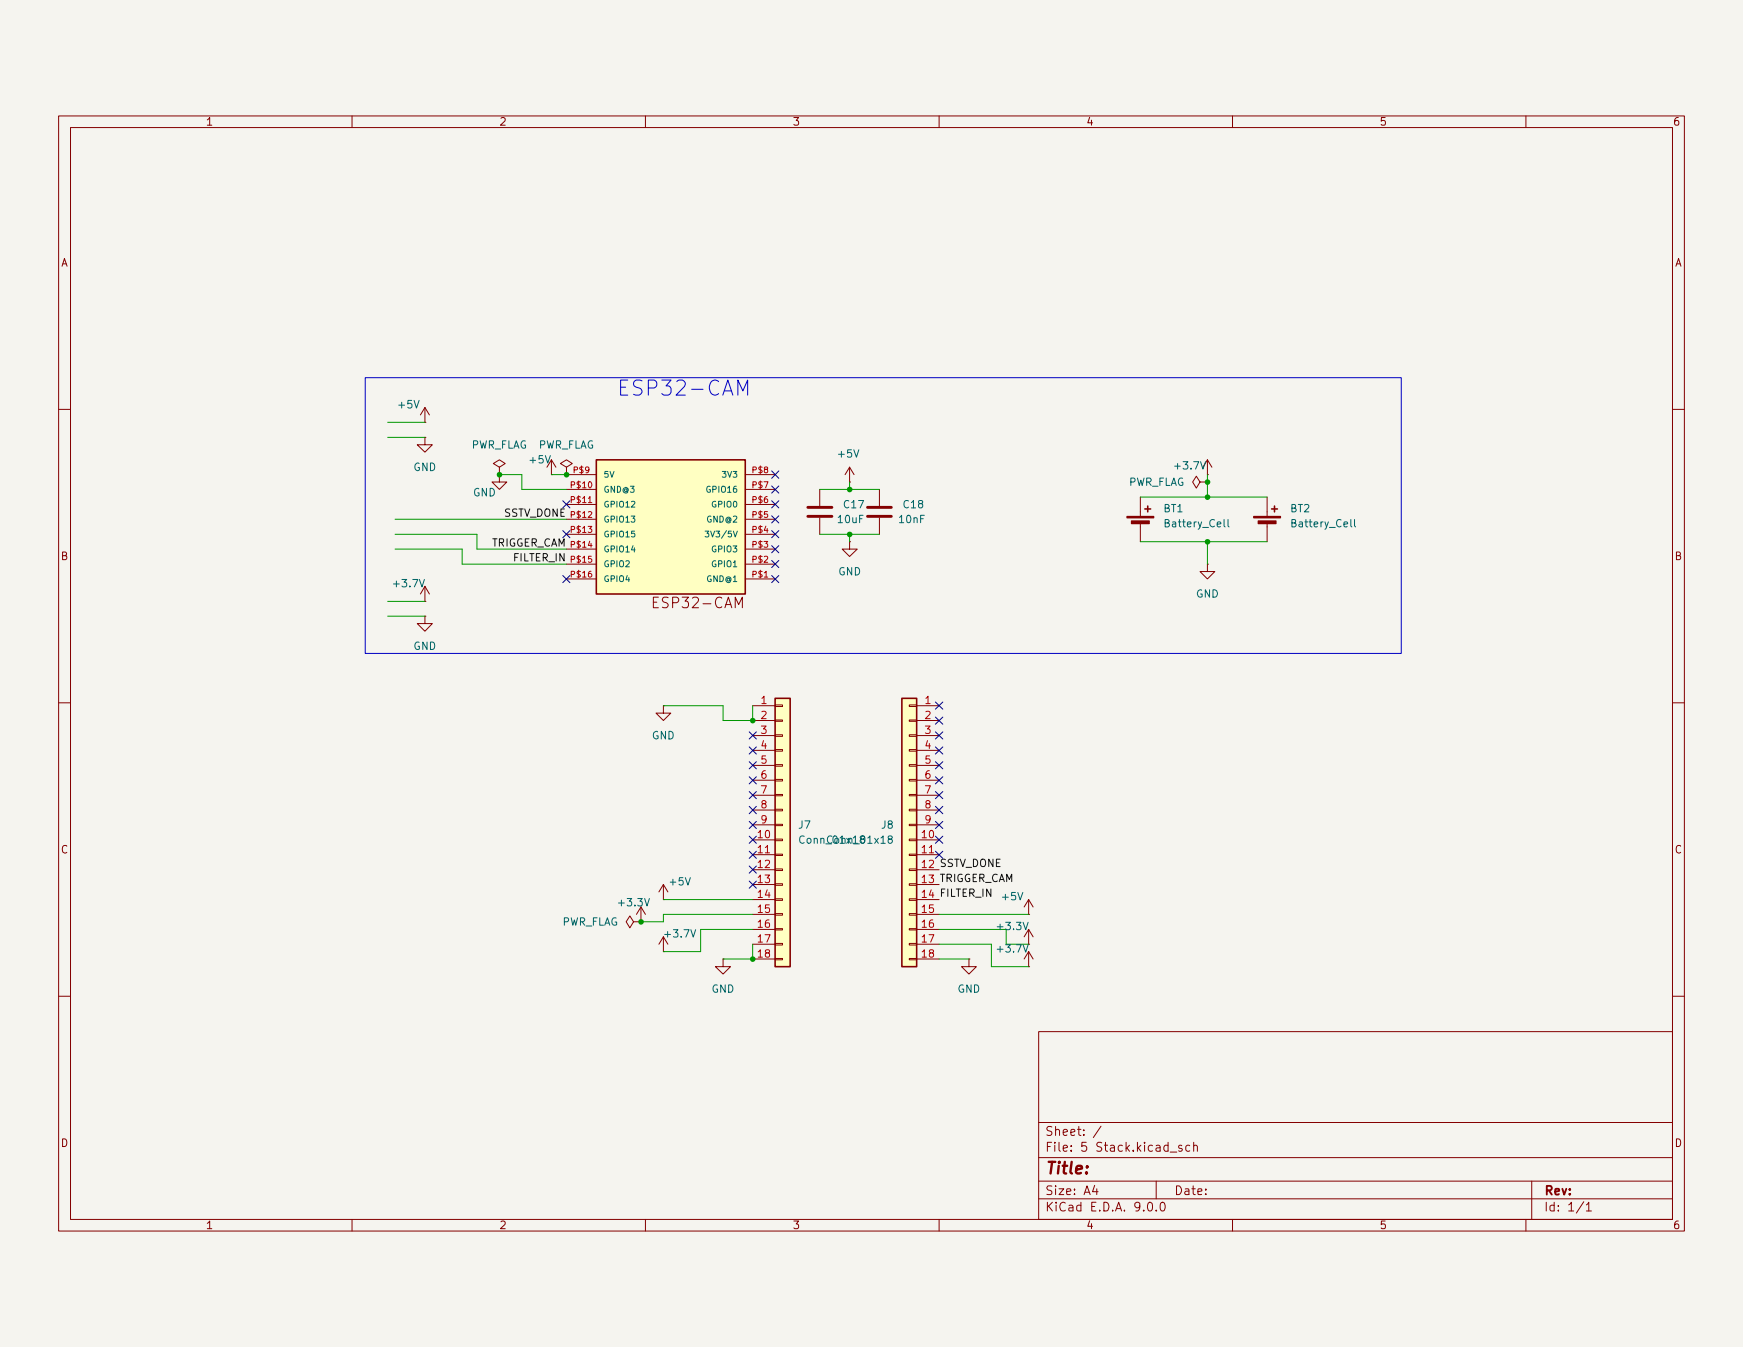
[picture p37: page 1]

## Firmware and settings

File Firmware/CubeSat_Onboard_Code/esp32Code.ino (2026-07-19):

#include <stdio.h>
#include "esp_timer.h"
#include <ctype.h>
#include <Wire.h>
#include <HardwareSerial.h>
#include <Adafruit_MCP23X17.h>
#include <driver/dac.h>
#include <math.h>
#include <MPU6050.h>
#include <Adafruit_Sensor.h>
#include <Adafruit_BMP085_U.h>
#include <QMC5883LCompass.h>
#include <TinyGPS++.h>
#include <Adafruit_INA219.h>
#include <SPI.h>
#include <LoRa.h>

// ============================================
// MCP23017
// ============================================
Adafruit_MCP23X17 mcp;

#define MCP_CTRL_APRS  3
#define MCP_PTT_VHF    4
#define MCP_CTRL_SSTV  2
#define MCP_PTT_UHF    5

// ============================================
// ESP32 PINS
// ============================================
#define DAC_APRS     DAC_CHANNEL_2
#define TX_VHF       13
#define RX_VHF       14
#define GPS_RX       17
#define GPS_TX       16
#define TRIGGER_PIN  25
#define NANO_RX      32
#define NANO_TX      27

// ============================================
// LORA PINS
// ============================================
#define LORA_SS    5
#define LORA_RST   33
#define LORA_DIO0  35
#define LORA_SCK   18
#define LORA_MOSI  23
#define LORA_MISO  34

// ============================================
// CALLSIGN
// ============================================
#define MY_CALLSIGN  "ABHI"
#define MY_SSID      10

// ============================================
// SERIAL
// ============================================
HardwareSerial Serial2Dev(2);
HardwareSerial SerialGPS(1);

// ============================================
// SENSORS
// ============================================
TinyGPSPlus             gps;
MPU6050                 mpu;
Adafruit_BMP085_Unified bmp(10085);
QMC5883LCompass         compass;
Adafruit_INA219         ina219;

const int MAG_OFFSET_X =  849;
const int MAG_OFFSET_Y =  217;
const int MAG_OFFSET_Z = -180;

float groundPressure   = 1013.25;
bool  groundCalibrated = false;

char  gps_lat_str[12] = "0000.00N";
char  gps_lon_str[12] = "00000.00E";
float gps_alt_m       = 0;
int   gps_sats        = 0;
bool  gps_valid       = false;

float bmp_temp = 0, bmp_pres = 0, bmp_alt = 0;
float imu_roll = 0, imu_pitch = 0, imu_yaw = 0;
float ax_g = 0, ay_g = 0, az_g = 0;
float gx_d = 0, gy_d = 0, gz_d = 0;
float mag_x = 0, mag_y = 0, mag_z = 0;
float ina_voltage = 0, ina_current = 0, ina_power = 0;

char info[120];

// ============================================
// LORA TIMING
// ============================================
unsigned long lastLoRaTX = 0;
#define LORA_INTERVAL  1000

// ============================================
// MODE
// ============================================
enum Mode { IDLE_MODE, APRS_MODE, SSTV_MODE };
Mode currentMode = IDLE_MODE;

// ============================================
// UART2 MODE
// ============================================
enum UARTMode { UART_NANO, UART_DRA818 };
UARTMode uart2Mode = UART_NANO;

void switchToNano()
{
  if (uart2Mode == UART_NANO) return;
  Serial2Dev.end();
  delay(50);
  Serial2Dev.begin(9600, SERIAL_8N1, NANO_RX, NANO_TX);
  uart2Mode = UART_NANO;
}

void switchToDRA818()
{
  if (uart2Mode == UART_DRA818) return;
  Serial2Dev.end();
  delay(50);
  Serial2Dev.begin(9600, SERIAL_8N1, RX_VHF, TX_VHF);
  uart2Mode = UART_DRA818;
}

// ============================================
// AFSK
// ============================================
const int   SAMPLE_RATE     = 9600;
const int   SAMPLES_PER_BIT = SAMPLE_RATE / 1200;
const float INC_MARK  = (2.0f * PI * 1200.0f) / SAMPLE_RATE;
const float INC_SPACE = (2.0f * PI * 2200.0f) / SAMPLE_RATE;

static uint8_t frame_bytes[300];
static bool    data_bits[4096];
static bool    bit_tones[4096];

volatile int  total_bits  = 0;
volatile int  cur_bit     = 0;
volatile int  samp_in_bit = 0;
volatile bool tx_active   = false;

float phase = 0;
esp_timer_handle_t audio_timer;

// ============================================
// DRA818
// ============================================
String readResp(uint16_t timeout = 800)
{
  unsigned long s = millis();
  String r;
  while (millis() - s < timeout)
    if (Serial2Dev.available())
      r += char(Serial2Dev.read());
  return r;
}

void bootDRA818()
{
  switchToDRA818();
  delay(1000);
  Serial2Dev.print("AT+DMOCONNECT\r\n");
  readResp();
  Serial2Dev.print("AT+DMOSETGROUP=0,144.8000,144.8000,0000,4,0000\r\n");
  readResp();
  Serial2Dev.print("AT+SETFILTER=0,0,0\r\n");
  readResp();
}

// ============================================
// CHECK DTMF
// ============================================
void checkDTMF()
{
  switchToNano();
  if (Serial2Dev.available()) {
    String cmd = Serial2Dev.readStringUntil('\n');
    cmd.trim();
    if (cmd.startsWith("CMD:")) {
      int val = cmd.substring(4).toInt();
      switch (val) {
        case 1: currentMode = IDLE_MODE; break;
        case 2: currentMode = APRS_MODE; break;
        case 3: currentMode = SSTV_MODE; break;
      }
    }
  }
}

// ============================================
// GPS FORMAT
// ============================================
void formatAPRSLat(float lat, char *out)
{
  char hemi = (lat >= 0) ? 'N' : 'S';
  lat = fabs(lat);
  int deg = (int)lat;
  float min = (lat - deg) * 60.0;
  snprintf(out, 12, "%02d%05.2f%c", deg, min, hemi);
}

void formatAPRSLon(float lon, char *out)
{
  char hemi = (lon >= 0) ? 'E' : 'W';
  lon = fabs(lon);
  int deg = (int)lon;
  float min = (lon - deg) * 60.0;
  snprintf(out, 12, "%03d%05.2f%c", deg, min, hemi);
}

// ============================================
// READ SENSORS
// ============================================
void readSensors()
{
  unsigned long gpsStart = millis();
  while (millis() - gpsStart < 500)
    if (SerialGPS.available())
      gps.encode(SerialGPS.read());

  if (gps.location.isValid()) {
    formatAPRSLat(gps.location.lat(), gps_lat_str);
    formatAPRSLon(gps.location.lng(), gps_lon_str);
    gps_alt_m = gps.altitude.meters();
    gps_sats  = gps.satellites.value();
    gps_valid = true;
  } else {
    gps_valid = false;
  }

  sensors_event_t event;
  bmp.getEvent(&event);
  if (event.pressure) {
    bmp_pres = event.pressure;
    bmp.getTemperature(&bmp_temp);
    if (!groundCalibrated) {
      groundPressure = bmp_pres;
      groundCalibrated = true;
    }
    bmp_alt = 44330.0 * (1.0 - pow(bmp_pres / groundPressure, 0.1903));
  }

  int16_t ax, ay, az, gx, gy, gz;
  mpu.getMotion6(&ax, &ay, &az, &gx, &gy, &gz);
  ax_g = ax / 16384.0;
  ay_g = ay / 16384.0;
  az_g = az / 16384.0;
  gx_d = gx / 131.0;
  gy_d = gy / 131.0;
  gz_d = gz / 131.0;

  compass.read();
  mag_x = (compass.getX() - MAG_OFFSET_X) * 0.0083333;
  mag_y = (compass.getY() - MAG_OFFSET_Y) * 0.0083333;
  mag_z = (compass.getZ() - MAG_OFFSET_Z) * 0.0083333;

  imu_roll  = atan2(ay_g, az_g) * 180.0 / PI;
  imu_pitch = atan2(-ax_g, sqrt(ay_g*ay_g + az_g*az_g)) * 180.0 / PI;

  float roll_r  = imu_roll  * PI / 180.0;
  float pitch_r = imu_pitch * PI / 180.0;
  float mx_comp = mag_x*cos(pitch_r) + mag_z*sin(pitch_r);
  float my_comp = mag_x*sin(roll_r)*sin(pitch_r)
                + mag_y*cos(roll_r)
                - mag_z*sin(roll_r)*cos(pitch_r);

  imu_yaw = atan2(my_comp, mx_comp) * 180.0 / PI;
  if (imu_yaw < 0) imu_yaw += 360.0;

  ina_voltage = ina219.getBusVoltage_V();
  ina_current = ina219.getCurrent_mA();
  ina_power   = ina219.getPower_mW();
}

// ============================================
// LORA SEND
// ============================================
void sendLoRa()
{
  String payload = "{";
  payload += "\"lat\":"  + String(gps.location.lat(), 6) + ",";
  payload += "\"lng\":"  + String(gps.location.lng(), 6) + ",";
  payload += "\"galt\":" + String(gps_alt_m, 1) + ",";
  payload += "\"sat\":"  + String(gps_sats) + ",";
  payload += "\"ax\":"   + String(ax_g, 2) + ",";
  payload += "\"ay\":"   + String(ay_g, 2) + ",";
  payload += "\"az\":"   + String(az_g, 2) + ",";
  payload += "\"gx\":"   + String(gx_d, 1) + ",";
  payload += "\"gy\":"   + String(gy_d, 1) + ",";
  payload += "\"gz\":"   + String(gz_d, 1) + ",";
  payload += "\"mx\":"   + String(mag_x, 1) + ",";
  payload += "\"my\":"   + String(mag_y, 1) + ",";
  payload += "\"mz\":"   + String(mag_z, 1) + ",";
  payload += "\"t\":"    + String(bmp_temp, 1) + ",";
  payload += "\"p\":"    + String(bmp_pres, 1) + ",";
  payload += "\"balt\":" + String(bmp_alt, 1) + ",";
  payload += "\"v\":"    + String(ina_voltage, 2) + ",";
  payload += "\"c\":"    + String(ina_current, 1) + ",";
  payload += "\"pw\":"   + String(ina_power, 1) + ",";
  payload += "\"r\":"    + String(imu_roll, 1) + ",";
  payload += "\"pi\":"   + String(imu_pitch, 1) + ",";
  payload += "\"y\":"    + String(imu_yaw, 1);
  payload += "}";

  LoRa.beginPacket();
  LoRa.print(payload);
  LoRa.endPacket();
}

// ============================================
// AX25
// ============================================
void encode_ax25_address(const char *call, int ssid, bool last, uint8_t *out)
{
  char buf[7] = "      ";
  for (int i = 0; call[i] && call[i] != '-' && i < 6; i++)
    buf[i] = toupper(call[i]);
  for (int i = 0; i < 6; i++) out[i] = buf[i] << 1;
  uint8_t ss = 0x60 | ((ssid & 0x0F) << 1);
  if (last) ss |= 1;
  out[6] = ss;
}

uint16_t ax25_crc(const uint8_t *data, int len)
{
  uint16_t crc = 0xFFFF;
  for (int i = 0; i < len; i++) {
    uint8_t b = data[i];
    for (int j = 0; j < 8; j++) {
      bool bit = (crc ^ b) & 1;
      crc >>= 1;
      if (bit) crc ^= 0x8408;
      b >>= 1;
    }
  }
  return ~crc;
}

int build_aprs_frame(const char *msg)
{
  int idx = 0; uint8_t a[7];
  encode_ax25_address("APRS", 0, false, a);
  memcpy(&frame_bytes[idx], a, 7); idx += 7;
  encode_ax25_address(MY_CALLSIGN, MY_SSID, true, a);
  memcpy(&frame_bytes[idx], a, 7); idx += 7;
  frame_bytes[idx++] = 0x03;
  frame_bytes[idx++] = 0xF0;
  while (*msg) frame_bytes[idx++] = *msg++;
  uint16_t crc = ax25_crc(frame_bytes, idx);
  frame_bytes[idx++] = crc & 0xFF;
  frame_bytes[idx++] = crc >> 8;
  return idx;
}

void build_bit_tones(const char *payload)
{
  int flen = build_aprs_frame(payload);
  int data_len = 0;
  const uint8_t FLAG = 0x7E;

  for (int f = 0; f < 30; f++)
    for (int i = 0; i < 8; i++)
      data_bits[data_len++] = (FLAG >> i) & 1;

  int ones = 0;
  for (int i = 0; i < flen; i++) {
    for (int j = 0; j < 8; j++) {
      bool b = (frame_bytes[i] >> j) & 1;
      data_bits[data_len++] = b;
      if (b) {
        ones++;
        if (ones == 5) { data_bits[data_len++] = 0; ones = 0; }
      } else { ones = 0; }
    }
  }

  for (int f = 0; f < 5; f++)
    for (int i = 0; i < 8; i++)
      data_bits[data_len++] = (FLAG >> i) & 1;

  bool mark = true;
  for (int i = 0; i < data_len; i++) {
    if (!data_bits[i]) mark = !mark;
    bit_tones[i] = mark;
  }
  total_bits = data_len;
  cur_bit = 0;
  samp_in_bit = 0;
}

// ============================================
// AUDIO ISR
// ============================================
void IRAM_ATTR audioCallback(void *)
{
  if (!tx_active || cur_bit >= total_bits) {
    dac_output_voltage(DAC_APRS, 128);
    return;
  }
  phase += bit_tones[cur_bit] ? INC_MARK : INC_SPACE;
  if (phase > 2*PI) phase -= 2*PI;
  dac_output_voltage(DAC_APRS, 128 + (int)(sinf(phase)*60));
  if (++samp_in_bit >= SAMPLES_PER_BIT) {
    samp_in_bit = 0;
    cur_bit++;
    if (cur_bit >= total_bits) tx_active = false;
  }
}

// ============================================
// SEND ONE APRS PACKET
// ============================================
void send_aprs(const char *msg)
{
  build_bit_tones(msg);
  phase = 0; cur_bit = 0; samp_in_bit = 0;

  mcp.digitalWrite(MCP_CTRL_APRS, HIGH);
  mcp.digitalWrite(MCP_PTT_VHF,   LOW);
  delay(1500);

  tx_active = true;
  while (tx_active) delay(1);

  mcp.digitalWrite(MCP_PTT_VHF,   HIGH);
  mcp.digitalWrite(MCP_CTRL_APRS, LOW);
}

// ============================================
// APRS — LoRa stopped during transmission
// ============================================
void runAPRS()
{
  switchToDRA818();
  readSensors();

  int alt_feet = (int)(gps_alt_m * 3.28084);

  snprintf(info, sizeof(info), "!%s/%s-/A=%06d",
    gps_lat_str, gps_lon_str, alt_feet);
  send_aprs(info); delay(3000);

  snprintf(info, sizeof(info), ">T:%.1fC P:%.1fhPa",
    bmp_temp, bmp_pres);
  send_aprs(info); delay(3000);

  snprintf(info, sizeof(info), ">BALT:%.1fm SATS:%d",
    bmp_alt, gps_sats);
  send_aprs(info); delay(3000);

  snprintf(info, sizeof(info), ">ROLL:%.1f PITCH:%.1f",
    imu_roll, imu_pitch);
  send_aprs(info); delay(3000);

  snprintf(info, sizeof(info), ">YAW:%.1f", imu_yaw);
  send_aprs(info); delay(3000);

  snprintf(info, sizeof(info), ">V:%.2f I:%.1fmA W:%.2f",
    ina_voltage, ina_current, ina_power);
  send_aprs(info); delay(3000);

  switchToNano();

  // Return to IDLE — LoRa will resume in main loop
  currentMode = IDLE_MODE;
}

// ============================================
// SSTV — LoRa stopped during transmission
// ============================================
void runSSTV()
{
  // Stop AFSK timer
  esp_timer_stop(audio_timer);
  dac_output_voltage(DAC_APRS, 128);

  pinMode(TRIGGER_PIN, OUTPUT);
  digitalWrite(TRIGGER_PIN, LOW);

  mcp.digitalWrite(MCP_CTRL_SSTV, HIGH);
  mcp.digitalWrite(MCP_PTT_UHF,   LOW);
  delay(600);

  digitalWrite(TRIGGER_PIN, HIGH);
  delay(20);
  digitalWrite(TRIGGER_PIN, LOW);

  unsigned long t0 = millis();
  while (millis() - t0 < 130000) {
    while (SerialGPS.available())
      gps.encode(SerialGPS.read());
    delay(1000);
  }

  mcp.digitalWrite(MCP_PTT_UHF,   HIGH);
  mcp.digitalWrite(MCP_CTRL_SSTV, LOW);

  // Restart AFSK timer
  esp_timer_start_periodic(audio_timer, 1000000 / SAMPLE_RATE);

  // Return to IDLE — LoRa will resume in main loop
  currentMode = IDLE_MODE;
}

// ============================================
// SETUP
// ============================================
void setup()
{
  Serial.begin(115200);

  Wire.begin(21, 22);

  if (!mcp.begin_I2C()) { while(1); }

  mcp.pinMode(MCP_CTRL_APRS, OUTPUT);
  mcp.pinMode(MCP_PTT_VHF,   OUTPUT);
  mcp.pinMode(MCP_CTRL_SSTV, OUTPUT);
  mcp.pinMode(MCP_PTT_UHF,   OUTPUT);
  mcp.digitalWrite(MCP_CTRL_APRS, LOW);
  mcp.digitalWrite(MCP_PTT_VHF,  HIGH);
  mcp.digitalWrite(MCP_CTRL_SSTV, LOW);
  mcp.digitalWrite(MCP_PTT_UHF,  HIGH);

  dac_output_enable(DAC_APRS);
  dac_output_voltage(DAC_APRS, 128);

  pinMode(TRIGGER_PIN, OUTPUT);
  digitalWrite(TRIGGER_PIN, LOW);

  Serial2Dev.begin(9600, SERIAL_8N1, NANO_RX, NANO_TX);
  uart2Mode = UART_NANO;

  SerialGPS.begin(9600, SERIAL_8N1, GPS_RX, GPS_TX);

  mpu.initialize();
  mpu.setI2CBypassEnabled(true);
  mpu.setSleepEnabled(false);

  if (!bmp.begin())    { while(1); }
  compass.init();
  if (!ina219.begin()) { while(1); }

  SPI.begin(LORA_SCK, LORA_MISO, LORA_MOSI, LORA_SS);
  LoRa.setPins(LORA_SS, LORA_RST, LORA_DIO0);
  if (!LoRa.begin(433E6)) { while(1); }

  bootDRA818();
  switchToNano();

  const esp_timer_create_args_t t = {
    .callback = &audioCallback,
    .name     = "afsk"
  };
  esp_timer_create(&t, &audio_timer);
  esp_timer_start_periodic(audio_timer, 1000000 / SAMPLE_RATE);

  currentMode = IDLE_MODE;
}

// ============================================
// LOOP
// ============================================
void loop()
{
  while (SerialGPS.available())
    gps.encode(SerialGPS.read());

  checkDTMF();

  switch (currentMode) {

    // LoRa runs continuously in IDLE
    case IDLE_MODE:
      if (millis() - lastLoRaTX >= LORA_INTERVAL) {
        readSensors();
        sendLoRa();
        lastLoRaTX = millis();
      }
      break;

    // APRS — LoRa stopped, after done -> IDLE -> LoRa resumes
    case APRS_MODE:
      runAPRS();
      break;

    // SSTV — LoRa stopped, after done -> IDLE -> LoRa resumes
    case SSTV_MODE:
      runSSTV();
      break;
  }
}

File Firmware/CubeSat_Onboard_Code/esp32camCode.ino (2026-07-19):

#include <Arduino.h>
#include "esp_camera.h"
#include "esp_timer.h"
#include <math.h>

// ===== PINS =====
#define AUDIO_PIN    2    // GPIO2  → LPF → CD4066 → SA868 MIC
#define TRIGGER_PIN  15   // GPIO14 → from ESP32 GPIO25
#define LED_FLASH    4    // GPIO4  → Flash LED

// ===== PWM =====
#define AUDIO_CH   0
#define PWM_FREQ   62500
#define PWM_BITS   8

// ===== SSTV =====
#define SAMPLE_RATE  11025
#define W  320
#define H  256

#define SYNC_US    4862
#define BLANK_US    572
#define SCAN_US  146432

#define SYNC_SAMPLES  ((uint32_t)((uint64_t)SAMPLE_RATE * SYNC_US  / 1000000ULL))
#define BLANK_SAMPLES ((uint32_t)((uint64_t)SAMPLE_RATE * BLANK_US / 1000000ULL))
#define SCAN_SAMPLES  ((uint32_t)((uint64_t)SAMPLE_RATE * SCAN_US  / 1000000ULL))

// ===== DDS =====
static int16_t sineLUT[256];
static volatile uint32_t phaseAcc  = 0;
static volatile uint32_t phaseStep = 0;

// ===== IMAGE BUFFER =====
uint8_t *rgbImage = nullptr;

// ===== AUDIO ISR =====
void IRAM_ATTR onAudioTimer(void *) {
  phaseAcc += phaseStep;
  uint8_t idx = phaseAcc >> 24;
  uint32_t pwm = ((int32_t)sineLUT[idx] + 32768) >> (16 - PWM_BITS);
  ledcWrite(AUDIO_CH, pwm);
}

inline void setTone(uint32_t f) {
  phaseStep = ((uint64_t)f << 32) / SAMPLE_RATE;
}

void toneSamples(uint32_t freq, uint32_t samples) {
  setTone(freq);
  delayMicroseconds((uint64_t)samples * 1000000ULL / SAMPLE_RATE);
}

inline int pixToFreq(uint8_t v) {
  return 1500 + (v * 800) / 255;
}

// ===== VIS CODE — Martin-1 =====
void sendVIS() {
  toneSamples(1900, SAMPLE_RATE * 300 / 1000);
  toneSamples(1200, SAMPLE_RATE * 10  / 1000);
  toneSamples(1900, SAMPLE_RATE * 300 / 1000);
  toneSamples(1200, SAMPLE_RATE * 30  / 1000);

  uint8_t vis = 44;  // Martin-1
  int ones = 0;
  for (int i = 0; i < 7; i++) {
    if (vis & (1 << i)) { toneSamples(1100, SAMPLE_RATE * 30 / 1000); ones++; }
    else                  toneSamples(1300, SAMPLE_RATE * 30 / 1000);
  }
  toneSamples((ones & 1) ? 1100 : 1300, SAMPLE_RATE * 30 / 1000);
  toneSamples(1200, SAMPLE_RATE * 30 / 1000);
}

// ===== CAMERA INIT =====
bool initCamera() {
  camera_config_t cfg = {
    .pin_pwdn     = 32,
    .pin_reset    = -1,
    .pin_xclk     = 0,
    .pin_sscb_sda = 26,
    .pin_sscb_scl = 27,
    .pin_d7       = 35,
    .pin_d6       = 34,
    .pin_d5       = 39,
    .pin_d4       = 36,
    .pin_d3       = 21,
    .pin_d2       = 19,
    .pin_d1       = 18,
    .pin_d0       = 5,
    .pin_vsync    = 25,
    .pin_href     = 23,
    .pin_pclk     = 22,
    .xclk_freq_hz = 20000000,
    .ledc_timer   = LEDC_TIMER_1,
    .ledc_channel = LEDC_CHANNEL_1,
    .pixel_format = PIXFORMAT_JPEG,
    .frame_size   = FRAMESIZE_QVGA,
    .jpeg_quality = 12,
    .fb_count     = 1,
    .fb_location  = CAMERA_FB_IN_PSRAM
  };
  return esp_camera_init(&cfg) == ESP_OK;
}

// ===== CAPTURE =====
bool captureImage() {
  camera_fb_t *fb = esp_camera_fb_get();
  if (!fb) return false;

  rgbImage = (uint8_t *)ps_malloc(W * H * 3);
  if (!rgbImage) { esp_camera_fb_return(fb); return false; }

  fmt2rgb888(fb->buf, fb->len, fb->format, rgbImage);
  esp_camera_fb_return(fb);
  return true;
}

// ===== SETUP =====
void setup() {
  Serial.begin(115200);
  Serial.println("\n=============================");
  Serial.println("   ESP32-CAM SSTV SYSTEM");
  Serial.println("=============================\n");

  // GPIO15 safe — must be LOW during boot
  // ESP32 GPIO25 idles LOW so this is safe
  pinMode(TRIGGER_PIN, INPUT_PULLDOWN);
  pinMode(LED_FLASH, OUTPUT);
  digitalWrite(LED_FLASH, LOW);

  // PWM — core 3.x API
  ledcAttachChannel(AUDIO_PIN, PWM_FREQ, PWM_BITS, AUDIO_CH);

  // Sine LUT
  for (int i = 0; i < 256; i++)
    sineLUT[i] = (int16_t)(sin(2.0 * PI * i / 256.0) * 16000);

  // Audio timer
  esp_timer_handle_t audioTimer;
  const esp_timer_create_args_t timerArgs = {
    .callback = &onAudioTimer,
    .name     = "sstv_audio"
  };
  esp_timer_create(&timerArgs, &audioTimer);
  esp_timer_start_periodic(audioTimer, 1000000 / SAMPLE_RATE);  // 90us

  // Camera init
  if (!initCamera()) {
    Serial.println("Camera FAIL — check module");
    while (1);
  }
  Serial.println("Camera OK");

  Serial.println("Waiting for trigger on GPIO15...");

  // Wait for trigger pulse from ESP32 GPIO25
  while (!digitalRead(TRIGGER_PIN)) delay(10);

  Serial.println("Triggered! Capturing image...");
  digitalWrite(LED_FLASH, HIGH);
  delay(100);
  digitalWrite(LED_FLASH, LOW);

  if (!captureImage()) {
    Serial.println("Capture FAIL");
    while (1);
  }
  Serial.println("Image captured OK");

  Serial.println("TX START — Martin-1 ~114 seconds");
  sendVIS();

  for (int y = 0; y < H; y++) {
    toneSamples(1200, SYNC_SAMPLES);

    auto scan = [&](int ch) {
      uint32_t prev = 0;
      for (int x = 0; x < W; x++) {
        uint32_t pos = ((uint64_t)(x + 1) * SCAN_SAMPLES) / W;
        uint32_t n   = pos - prev;
        prev = pos;
        uint8_t pix = rgbImage[(y * W + x) * 3 + ch];
        toneSamples(pixToFreq(pix), n);
      }
    };

    scan(1); toneSamples(1500, BLANK_SAMPLES);  // Green
    scan(0); toneSamples(1500, BLANK_SAMPLES);  // Blue
    scan(2);                                     // Red

    if (y % 32 == 0) {
      Serial.print("Line ");
      Serial.print(y);
      Serial.print(" / ");
      Serial.println(H);
    }
  }

  Serial.println("TX DONE");
}

void loop() {}
